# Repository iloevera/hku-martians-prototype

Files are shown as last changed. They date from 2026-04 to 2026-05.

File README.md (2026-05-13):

# HKU Martians Prototype Rover

Rudimentary 2-layer all-in-one Power Distribution Board (PDB) and logic carrier designed for small 6-wheel rovers with a 4-DoF robotic arm.

PCB preview

## 🚀 Key Specifications
- **Dimensions:** 99.57 x 99.06 mm
- **Power Input:** 6S LiPo (22.2V nominal, 25.2V max) via XT60.
- **Power Tree:**
  - **12V @ 10.8A:** High-current rail for BLDC/DC Main Drive motors. External module attached through XT30 connectors
  - **7.5V @ 5A:** Dedicated HV Servo rail (Optimized for 7.4V nominal servos). External module attached through XT30 connectors
  - **5.1V @ 5A:** On-board stabilized logic power for Pi 5 and peripherals. 3V3 Using Pico's built-in regulator.
- **Processing:**
  - Dual-core architecture: Raspberry Pi 5 (Thinking) + Pi Pico 2 (Doing).
  - UART communication bridge.
- **Actuation & Sensing:**
  - 6x PWM Encoder inputs.
  - 6x PWM-Controlled DC motor driver headers.
  - 4x High-Torque Servo ports with localized bulk capacitance.
  - Integrated 6S Battery Fuel Gauge (Voltage Divider + ADC).

## 🛠 Hardware Setup
### Battery Monitor Calibration
The internal voltage divider uses a **100kΩ (Top)** and **13.7kΩ (Bottom)** 1% precision resistor set. 
- **Max Input:** 25.2V
- **ADC Output:** ~3.03V
- **Safety Factor:** 10% headroom to prevent Pico ADC overvoltage.

### Communication
The Pi 5 and Pico 2 communicate via UART.
- **Baud Rate:** 115200 (Default)
- **Pinout:** Pi GPIO 14/15 <-> Pico GPIO 0/1.

## ⚠️ Assembly Warnings
1. **Thermal Reliefs:** High-current pads (XT60, Regulators, Motors) have thermal reliefs **DISABLED**. Use a high-power chisel-tip iron and pre-heat the board to 100°C for assembly.
2. **Capacitors:** Ensure C1 & C2 (2000uF) is rated for 50V minimum.
3. **USB Isolation:** Always use a USB isolator when debugging the Pi/Pico while the main battery is connected to prevent back-powering your PC.

## 📜 License
This project is released under CERN-OHL-W-2.0 license. Designed by **Ilo Japar / HKU Martians**.

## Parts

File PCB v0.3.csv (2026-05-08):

Reference | Qty | Value | Taobao
C1,C6 | 2 | 1000u 50V (E) | https://item.taobao.com/item.htm?id=522579424493&skuId=4292850932858
C2,C3,C9 | 3 | 0.1u 50V 1206 (C) | https://item.taobao.com/item.htm?id=522554243102
C4 | 1 | 100n 50V 1206 (C) | https://item.taobao.com/item.htm?id=522554243102
C5,C7 | 2 | 470u 50V (E) | https://item.taobao.com/item.htm?id=565000050337&skuId=4839680676732
C8 | 1 | 100u 50V (E) | https://item.taobao.com/item.htm?id=564996742055&skuId=5731925888317
D1 | 1 | 14.7V | https://item.taobao.com/item.htm?id=695101953366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
D2 | 1 | SK1010C | https://item.taobao.com/item.htm?id=661190438436
D3 | 1 | SMAJ6.0A | https://item.taobao.com/item.htm?id=626801460817
D4,D5,D6,D7 | 4 | Green 0805 | https://item.taobao.com/item.htm?id=522554271548&skuId=5766142345201
F1 | 1 | 15A | https://item.taobao.com/item.htm?id=646550973988&upStreamPrice=131&skuId=5317343647485
F2 | 1 | 5A 1812 | https://detail.tmall.com/item.htm?id=680110340340&xxc=shop&skuId=5053061151671
J1 | 1 | XT60-M | https://item.taobao.com/item.htm?from=cart&id=635227665423&skuId=4544457080563&upStreamPrice=247
J2 | 1 | Raspberry Pi 5 | https://item.taobao.com/item.htm?id=522576768218&skuId=3150252041904
J3,J5 | 2 | XT30-F | https://item.taobao.com/item.htm?from=cart&id=635227665423&skuId=4544457080563&upStreamPrice=247
J4,J6 | 2 | XT30-M | https://item.taobao.com/item.htm?from=cart&id=635227665423&skuId=4544457080563&upStreamPrice=247
J7,J8,J9,J10 | 4 | 2.54mm 3P | https://item.taobao.com/item.htm?id=522579376259&skuId=6139961763384
J11,J12,J13,J14,J15,J16 | 6 | 2.54mm 5P Terminal Block | https://item.taobao.com/item.htm?id=642057328277&skuId=4619071856328
J17,J18,J19,J20,J21,J22 | 6 | JST-SH 3P | https://item.taobao.com/item.htm?id=616913039189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
Q1 | 1 | NCE15P25JK | https://item.taobao.com/item.htm?from=cart&id=810052647977&upStreamPrice=155
R1,R2 | 2 | 100k 0805 1% | https://item.taobao.com/item.htm?id=526088038633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
R3 | 1 | 13.3k 0805 1% | https://item.taobao.com/item.htm?id=526088038633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
R4,R5,R6,R7,R8,R9 | 6 | 470R 0805 | https://item.taobao.com/item.htm?id=522573121620&skuId=5702455484812
TP1,TP2,TP3,TP4,TP5,TP6 | 6 | TestPoint
U1 | 1 | 3.2~32V -> 5.1V 5A | https://item.taobao.com/item.htm?id=530479908999

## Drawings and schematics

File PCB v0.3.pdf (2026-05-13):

GPIO0 1 | GPIO1 2 | GND

# ADC_VREF 35 ³V3 36

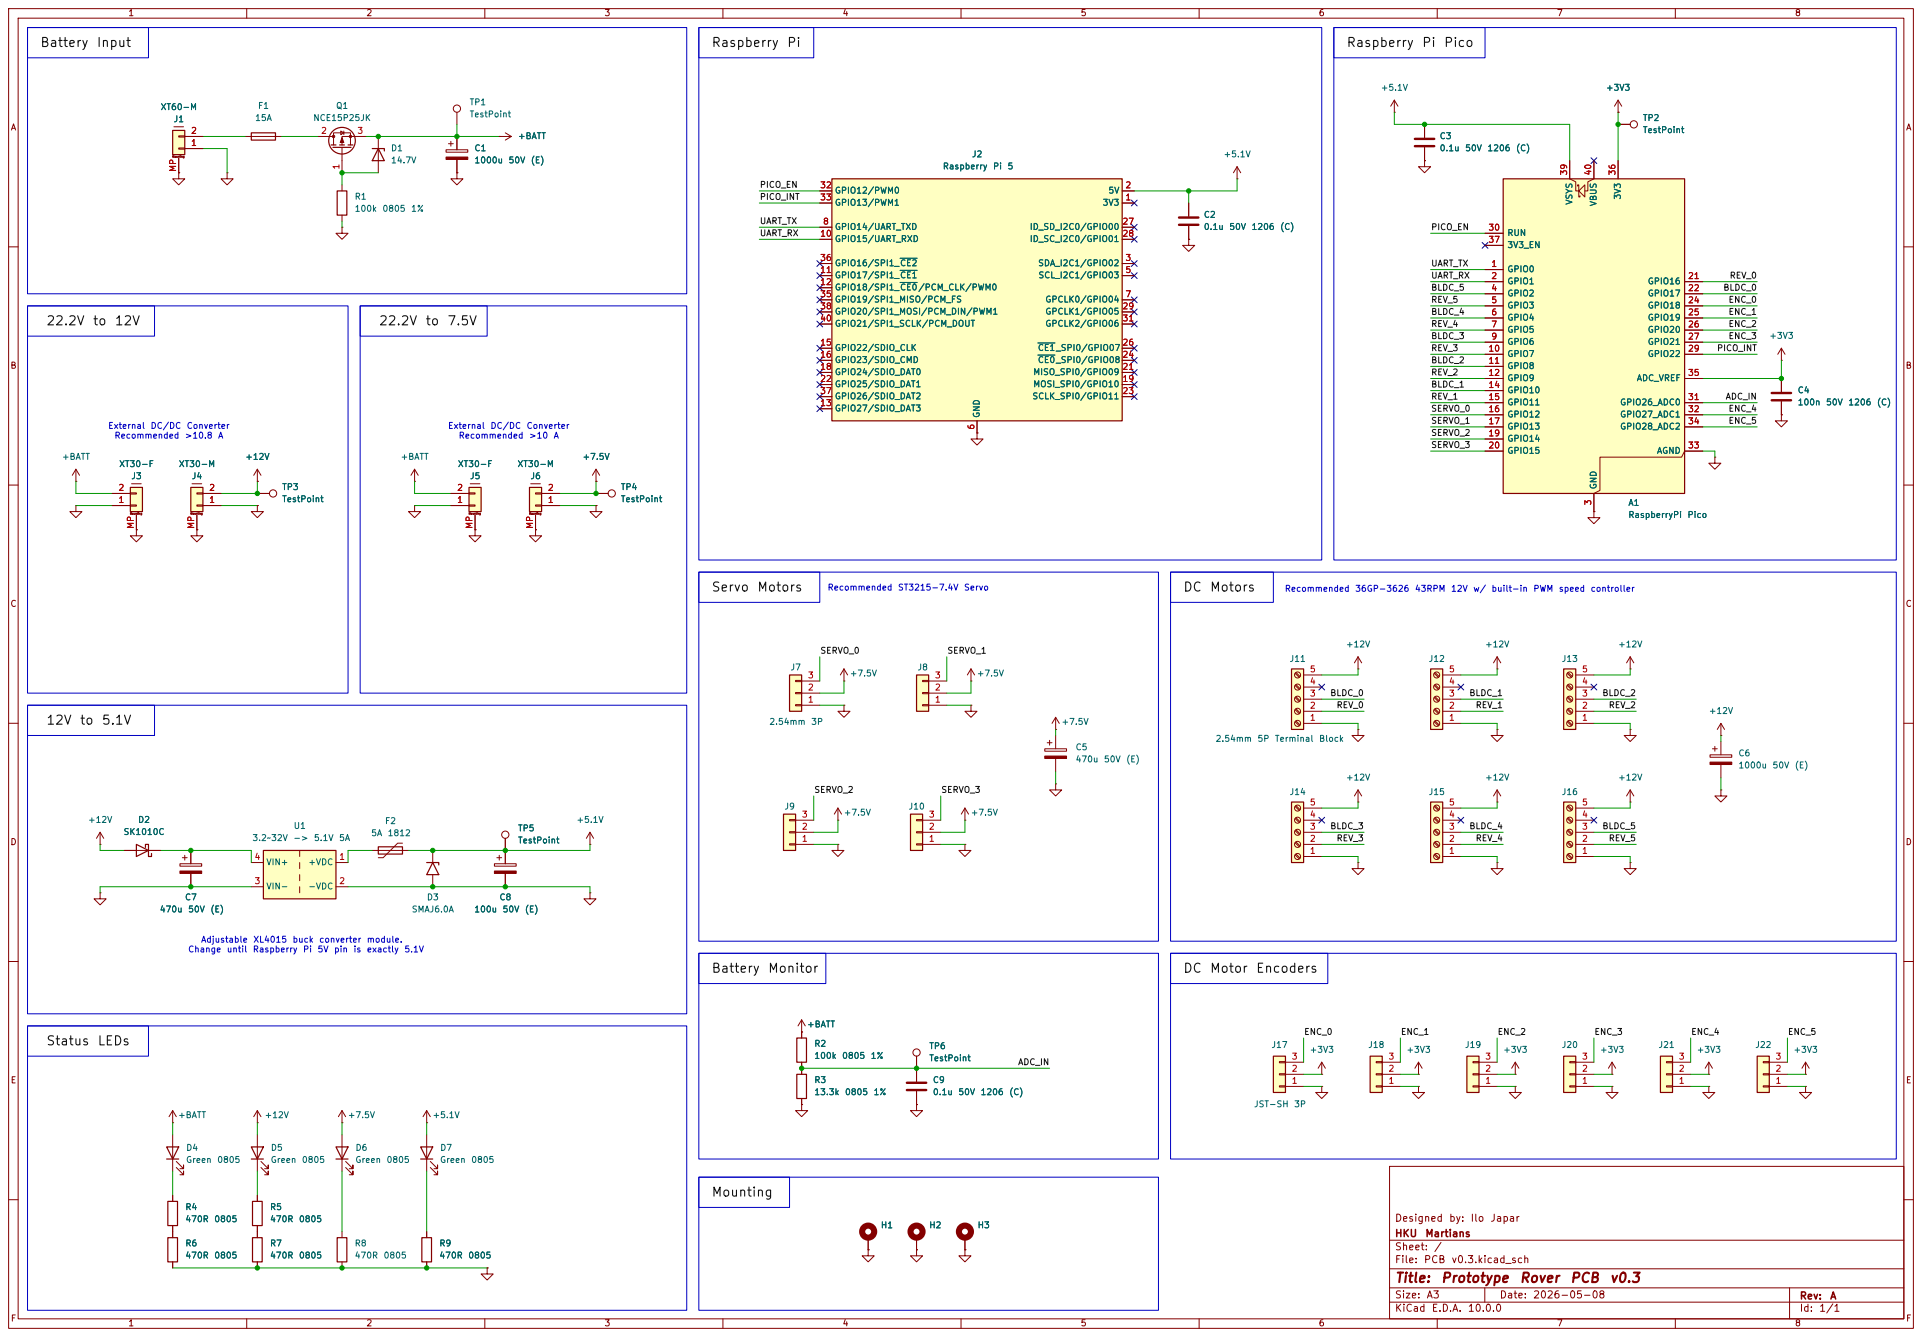
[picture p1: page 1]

Sheet: /
File: PCB v0.3.kicad_sch
Title: Prototype Rover PCB v0.3
F Date: 2026⁻05⁻08 KiCad E.D.A. 10.0.0

Q1 U1 | 99.57 mm 99.06 mm

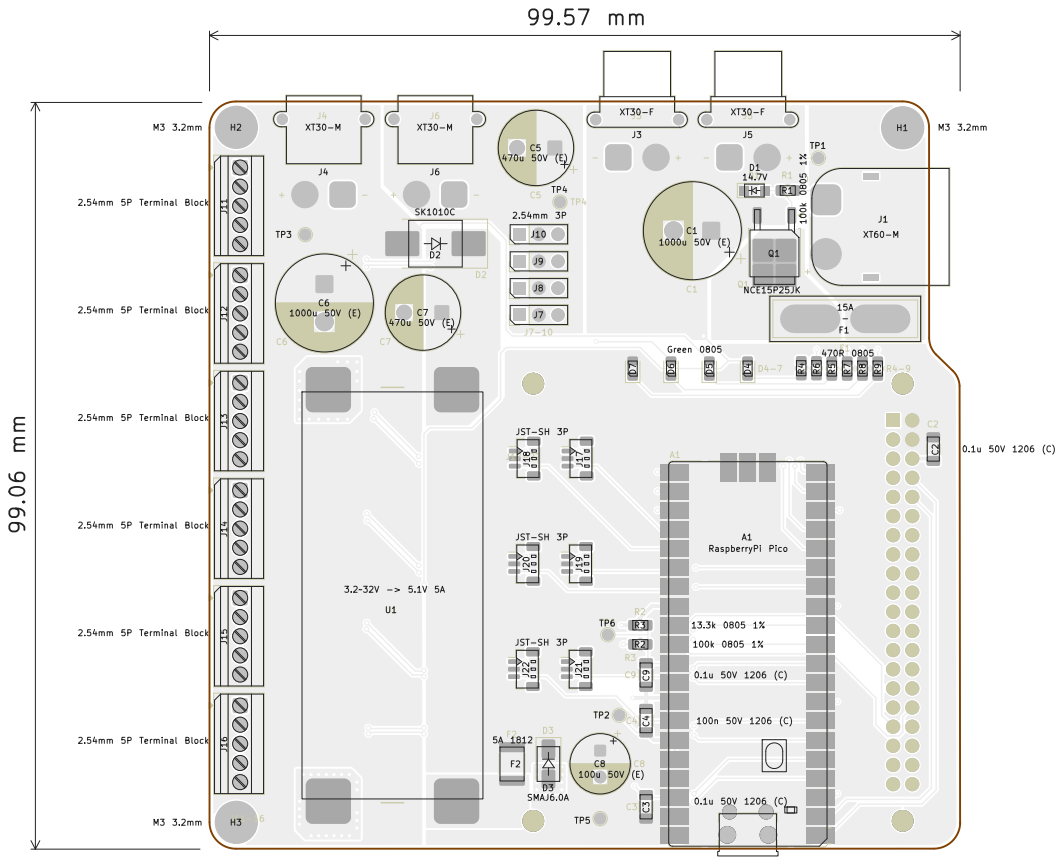
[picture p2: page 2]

Board2Pdf: Light Colors Placement TOP - Page 1/2

Sheet: Light Colors Placement TOP HKU Martians Designed by: Ilo Japar

D Date: 2026⁻04⁻10 KiCad E.D.A. 10.0.0
File: PCB v0.3.kicad_pcb
Title: Prototype Rover PCB v0.3

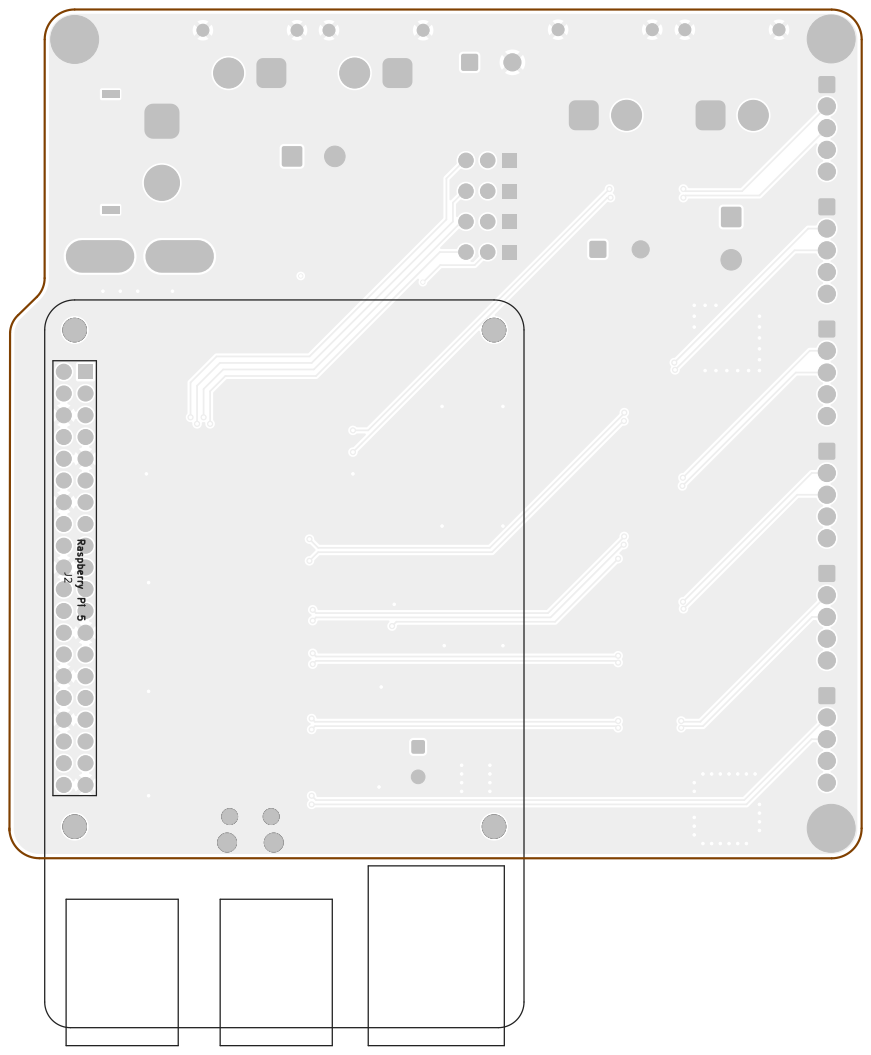
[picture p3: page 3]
J2 Raspberry Pi 5 1 2 3 4 5 6

Board2Pdf: Light Colors Placement BOT - Page 2/2

Sheet: Light Colors Placement BOT HKU Martians Designed by: Ilo Japar

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

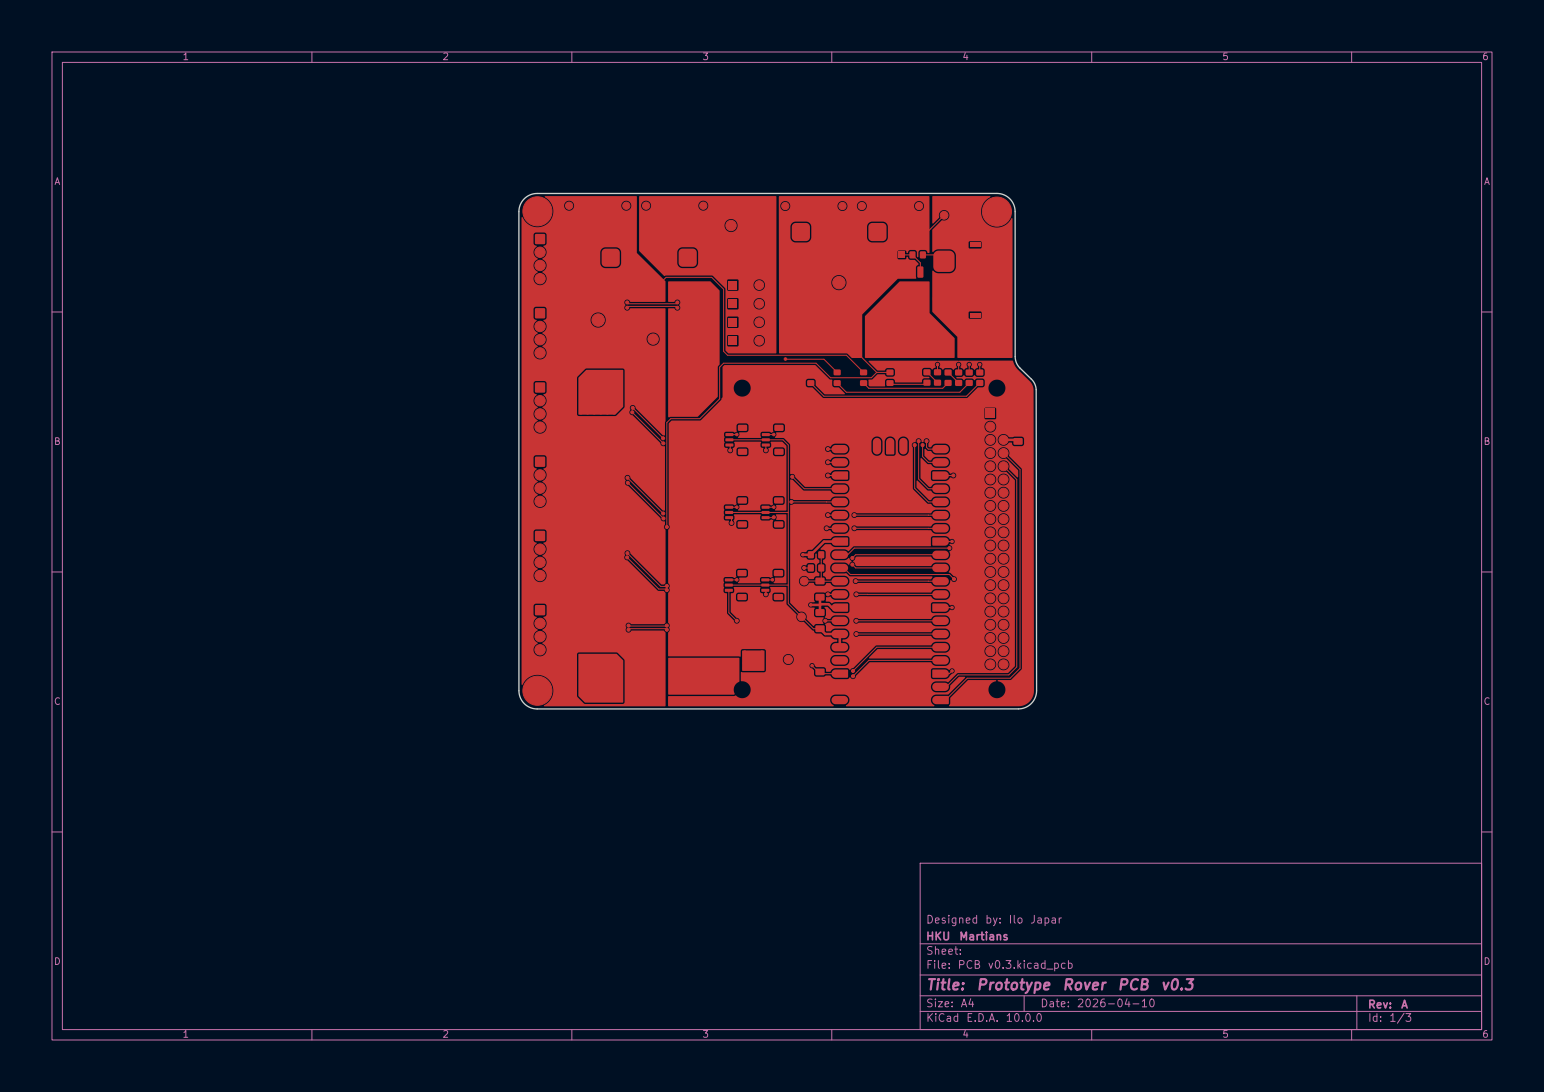
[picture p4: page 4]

HKU Martians Designed by: Ilo Japar

Sheet:
D Date: 2026⁻04⁻10 KiCad E.D.A. 10.0.0
File: PCB v0.3.kicad_pcb
Title: Prototype Rover PCB v0.3

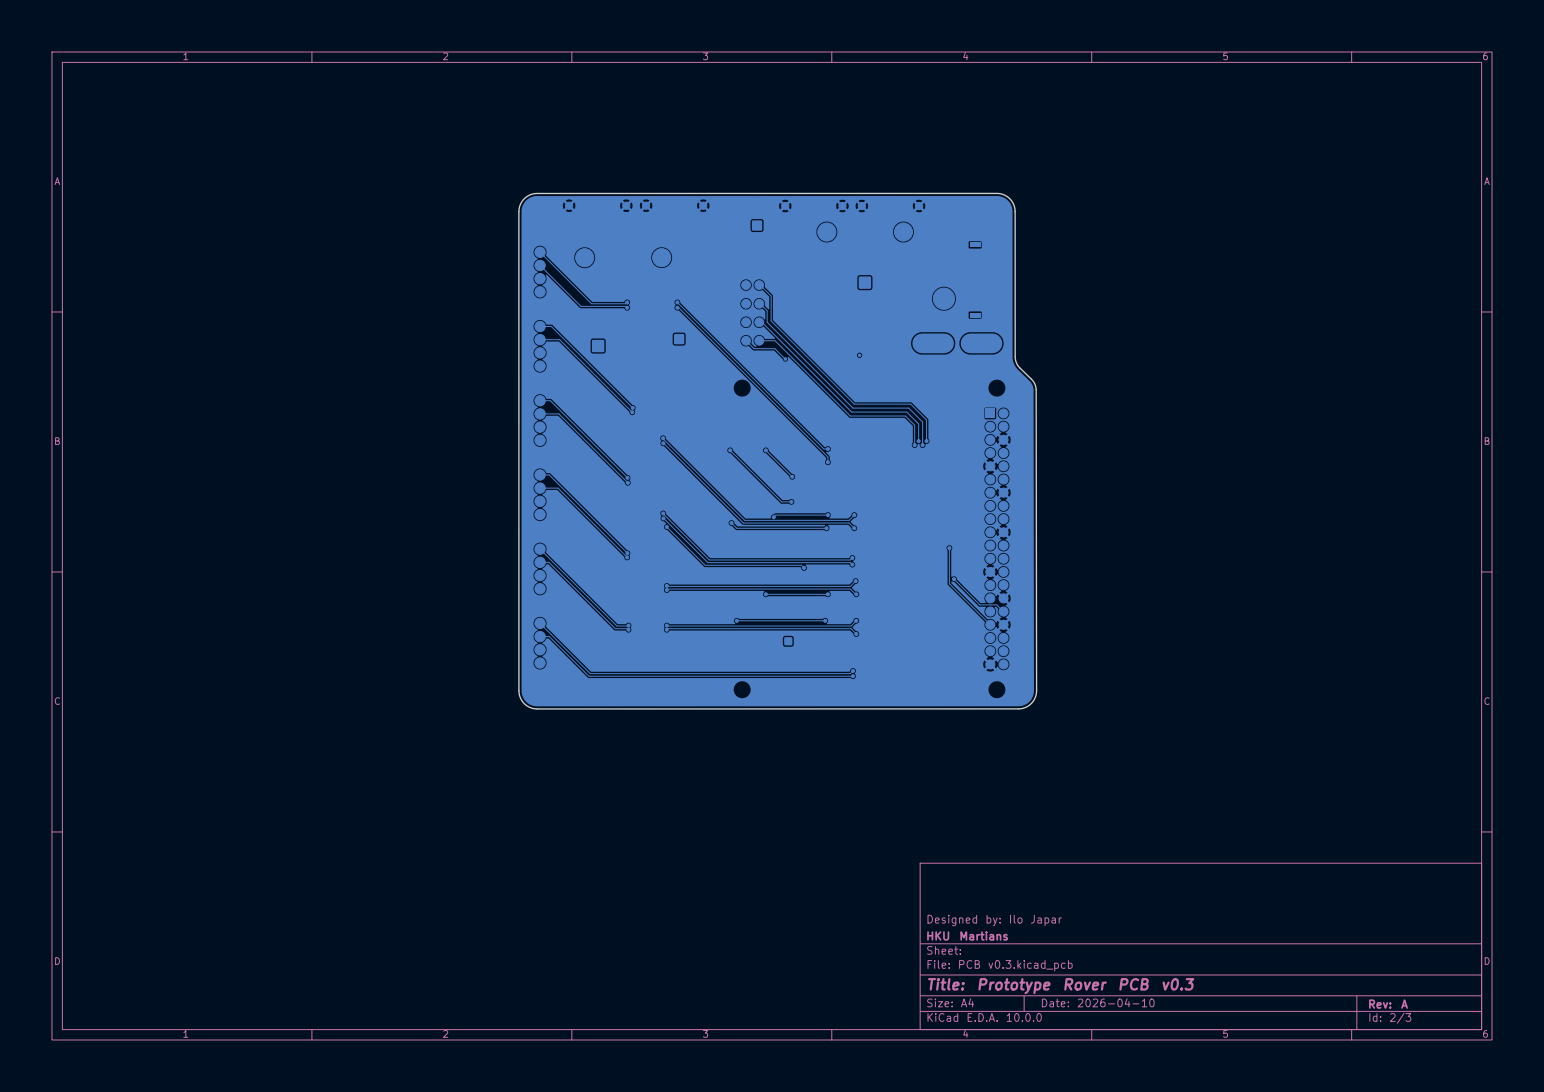
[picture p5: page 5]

HKU Martians Designed by: Ilo Japar

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

F2 | R2 C5 | R3

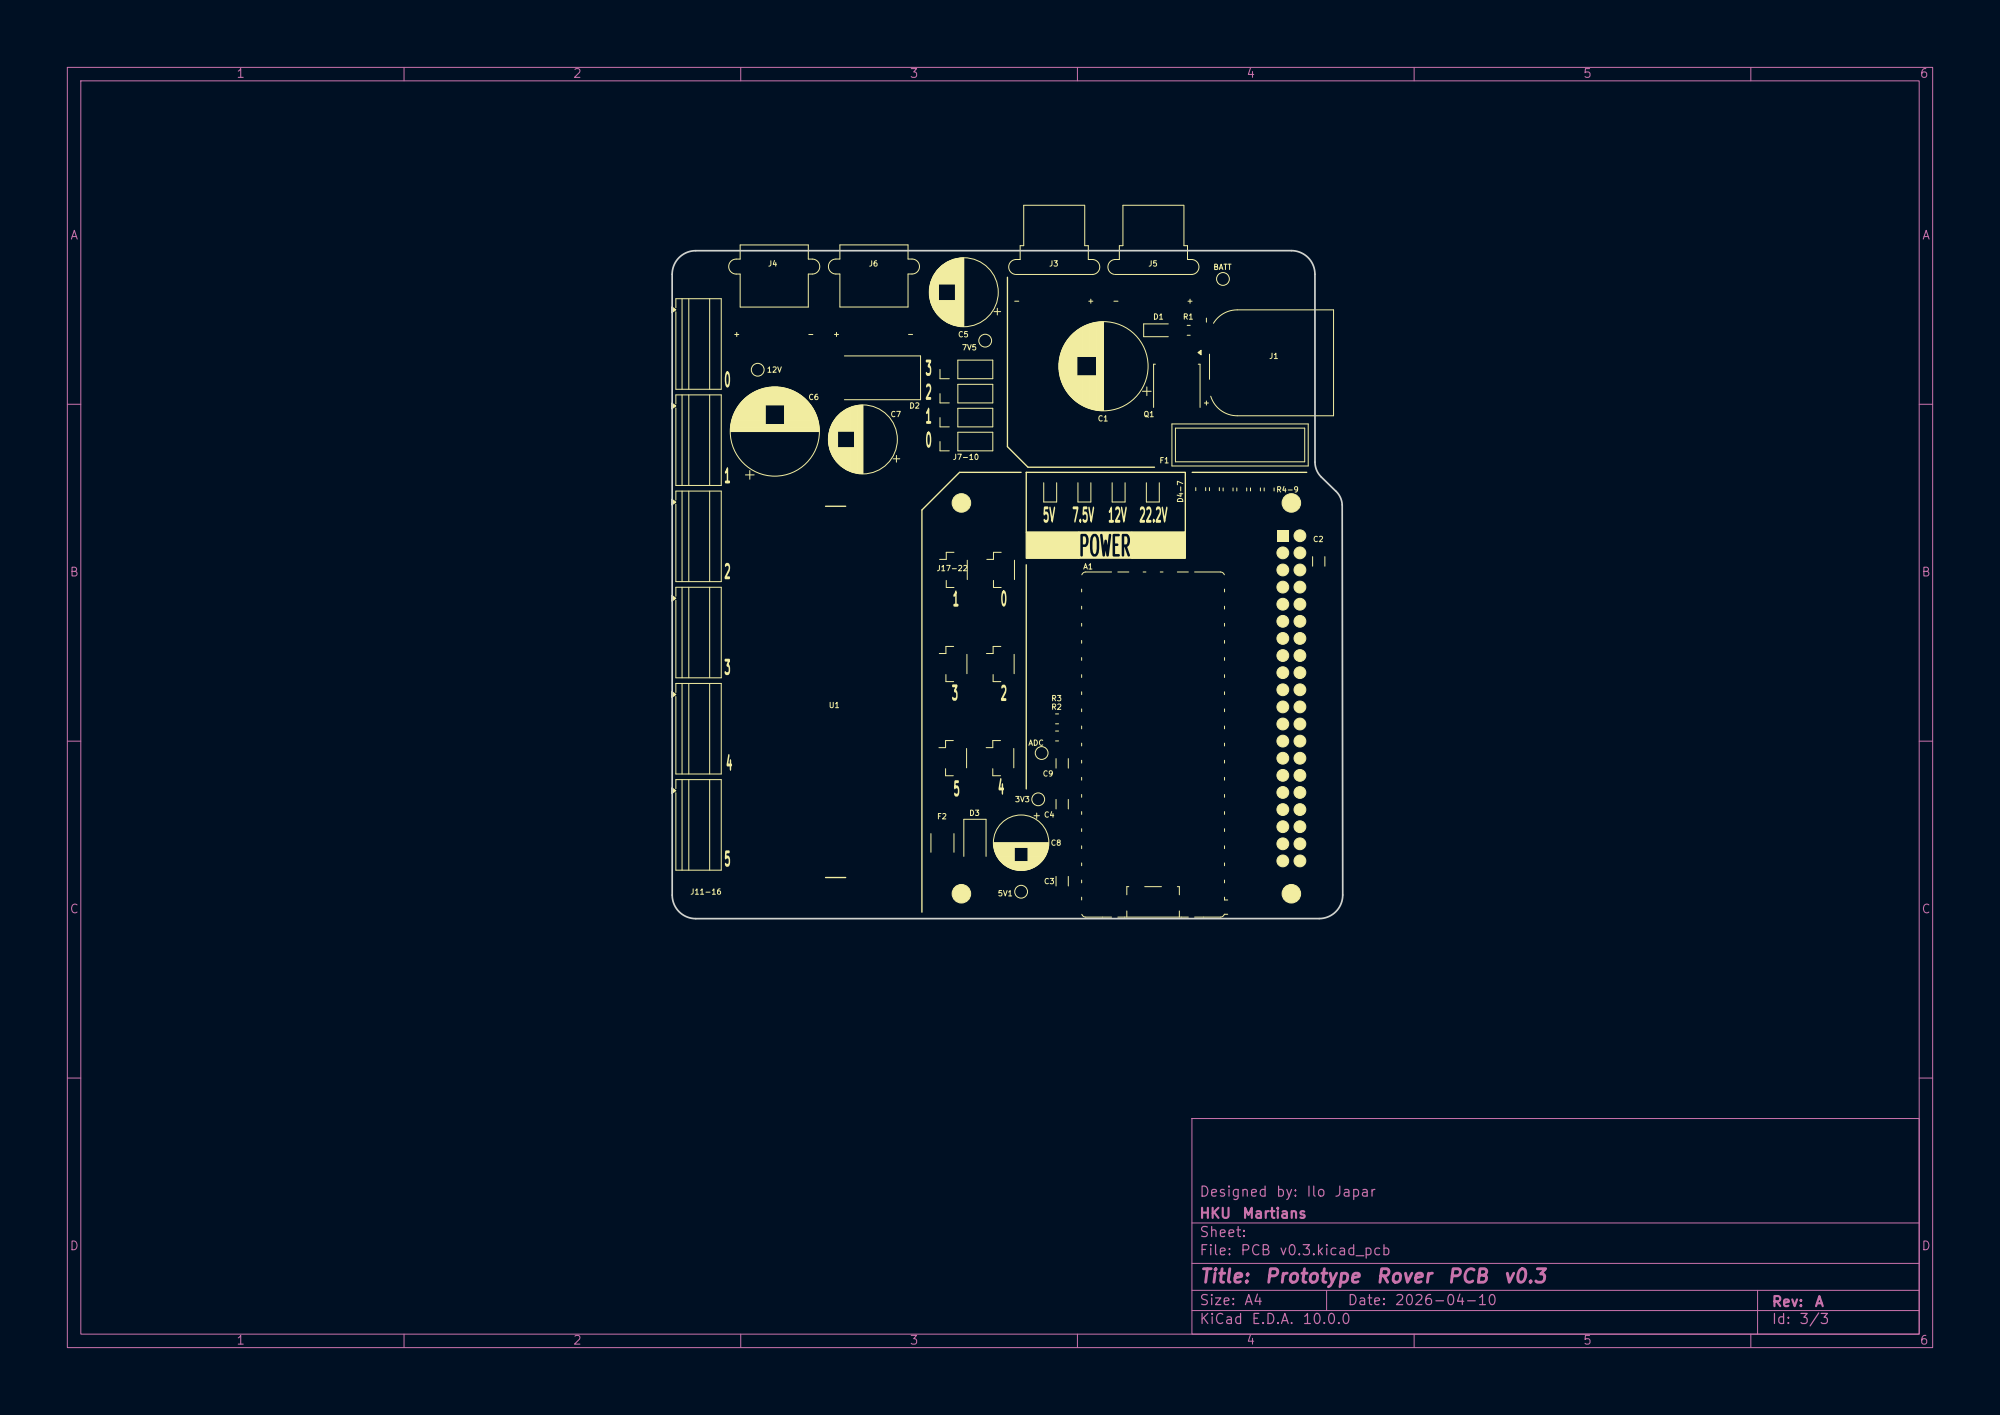
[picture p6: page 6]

HKU Martians Designed by: Ilo Japar

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

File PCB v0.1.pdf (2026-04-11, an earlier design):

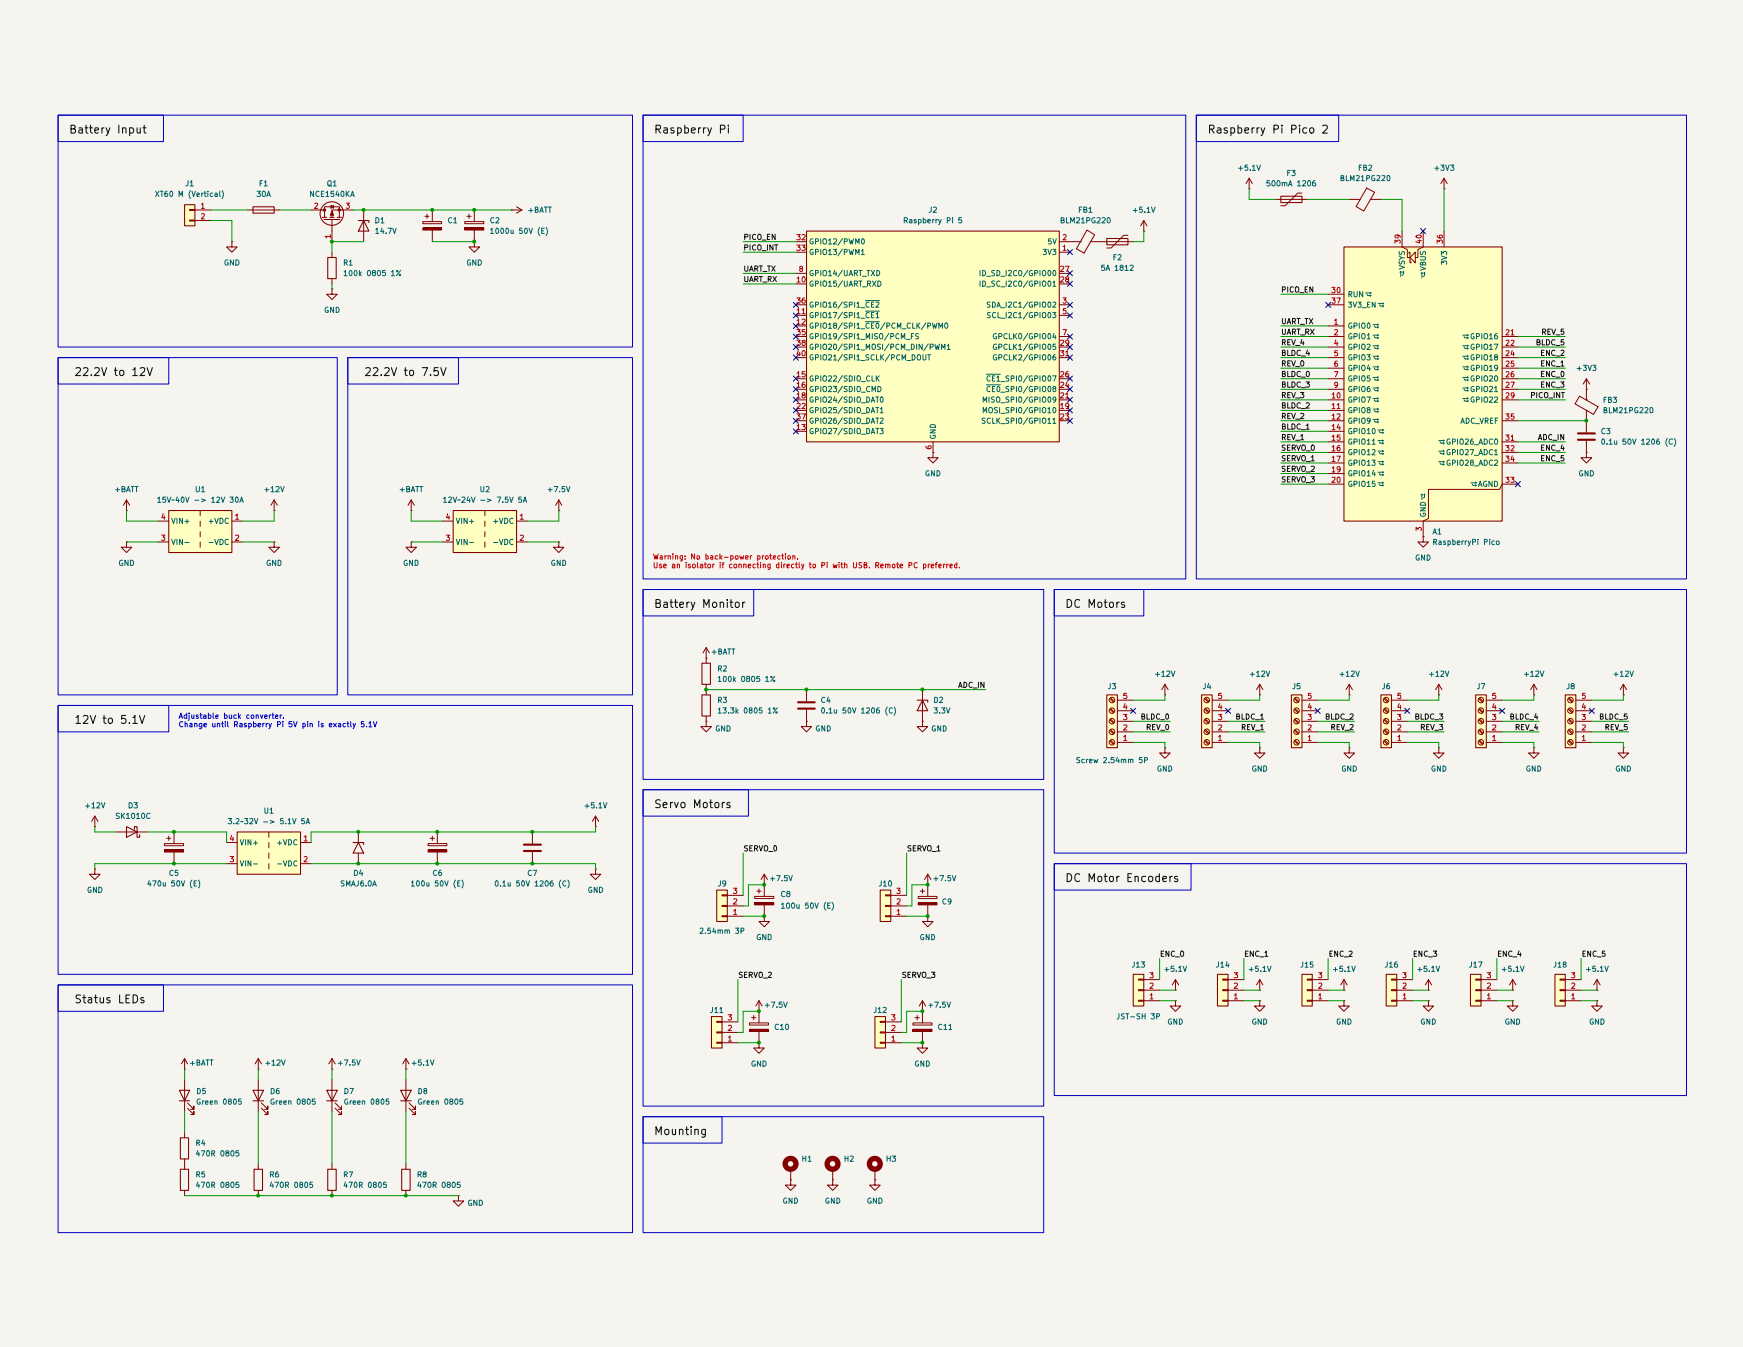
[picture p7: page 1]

# J3⁻8 D5⁻⁸ R4⁻⁸ J13⁻¹⁸

J6 | R5 SK1010C D3 | 2.54mm ³P J12

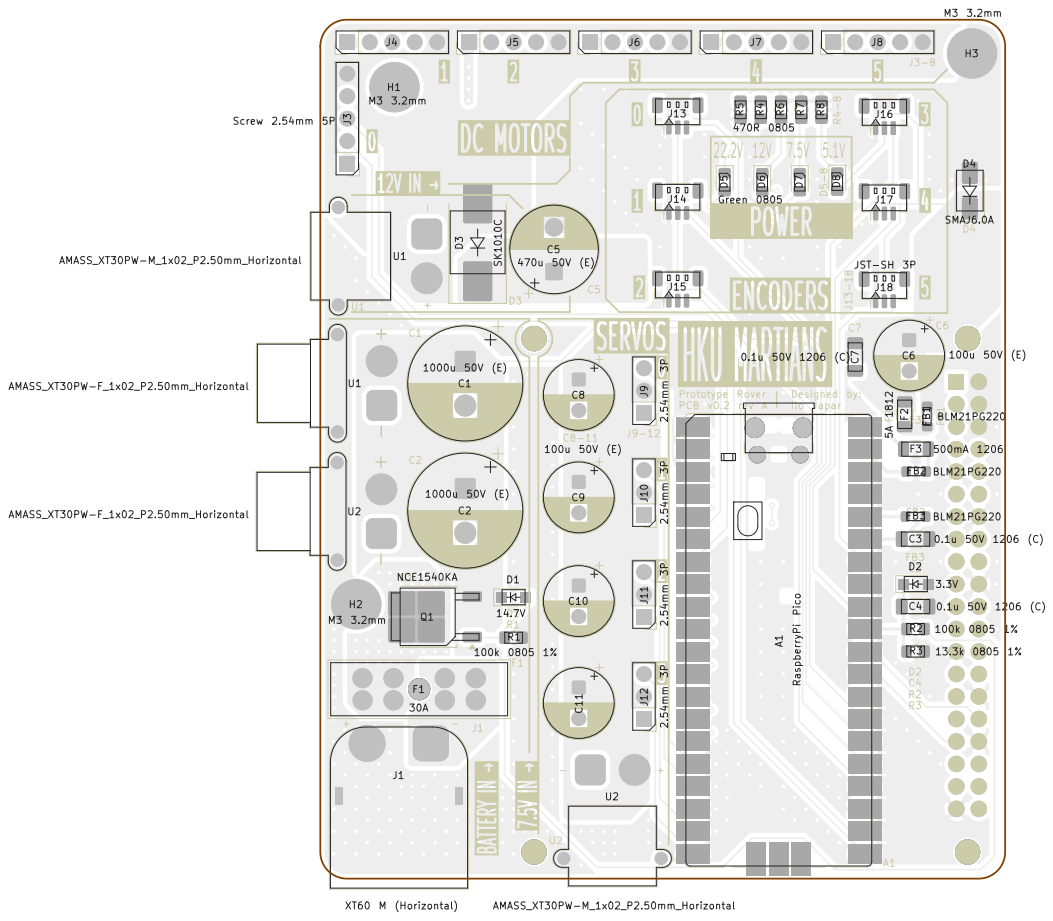
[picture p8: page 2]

Board2Pdf: Light Colors Placement TOP - Page 1/2

Designed by: Ilo Japar
Sheet: Light Colors Placement TOP HKU ROVER Team

D Date: 2026⁻04⁻10 KiCad E.D.A. 10.0.0
File: PCB v0.1.kicad_pcb
Title: Prototype Rover PCB v0.1

AB

AB

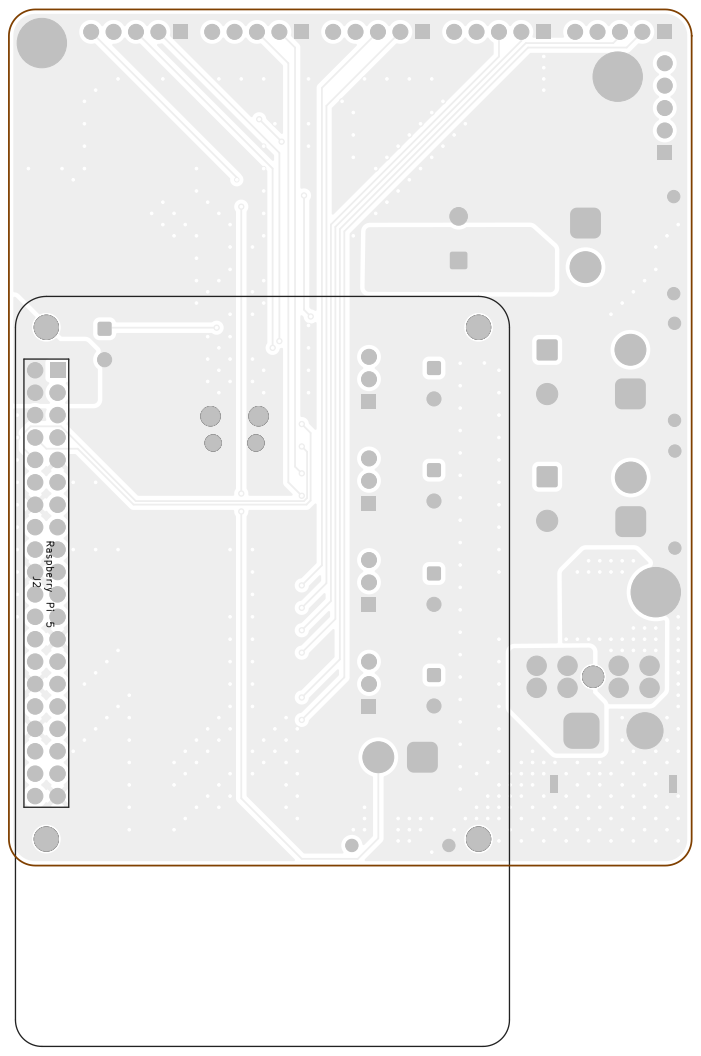
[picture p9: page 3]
J2 Raspberry Pi 5 1 2 3 4 5 6; Size: A4; Rev: A

Board2Pdf: Light Colors Placement BOT - Page 2/2

Designed by: Ilo Japar
Sheet: Light Colors Placement BOT HKU ROVER Team

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

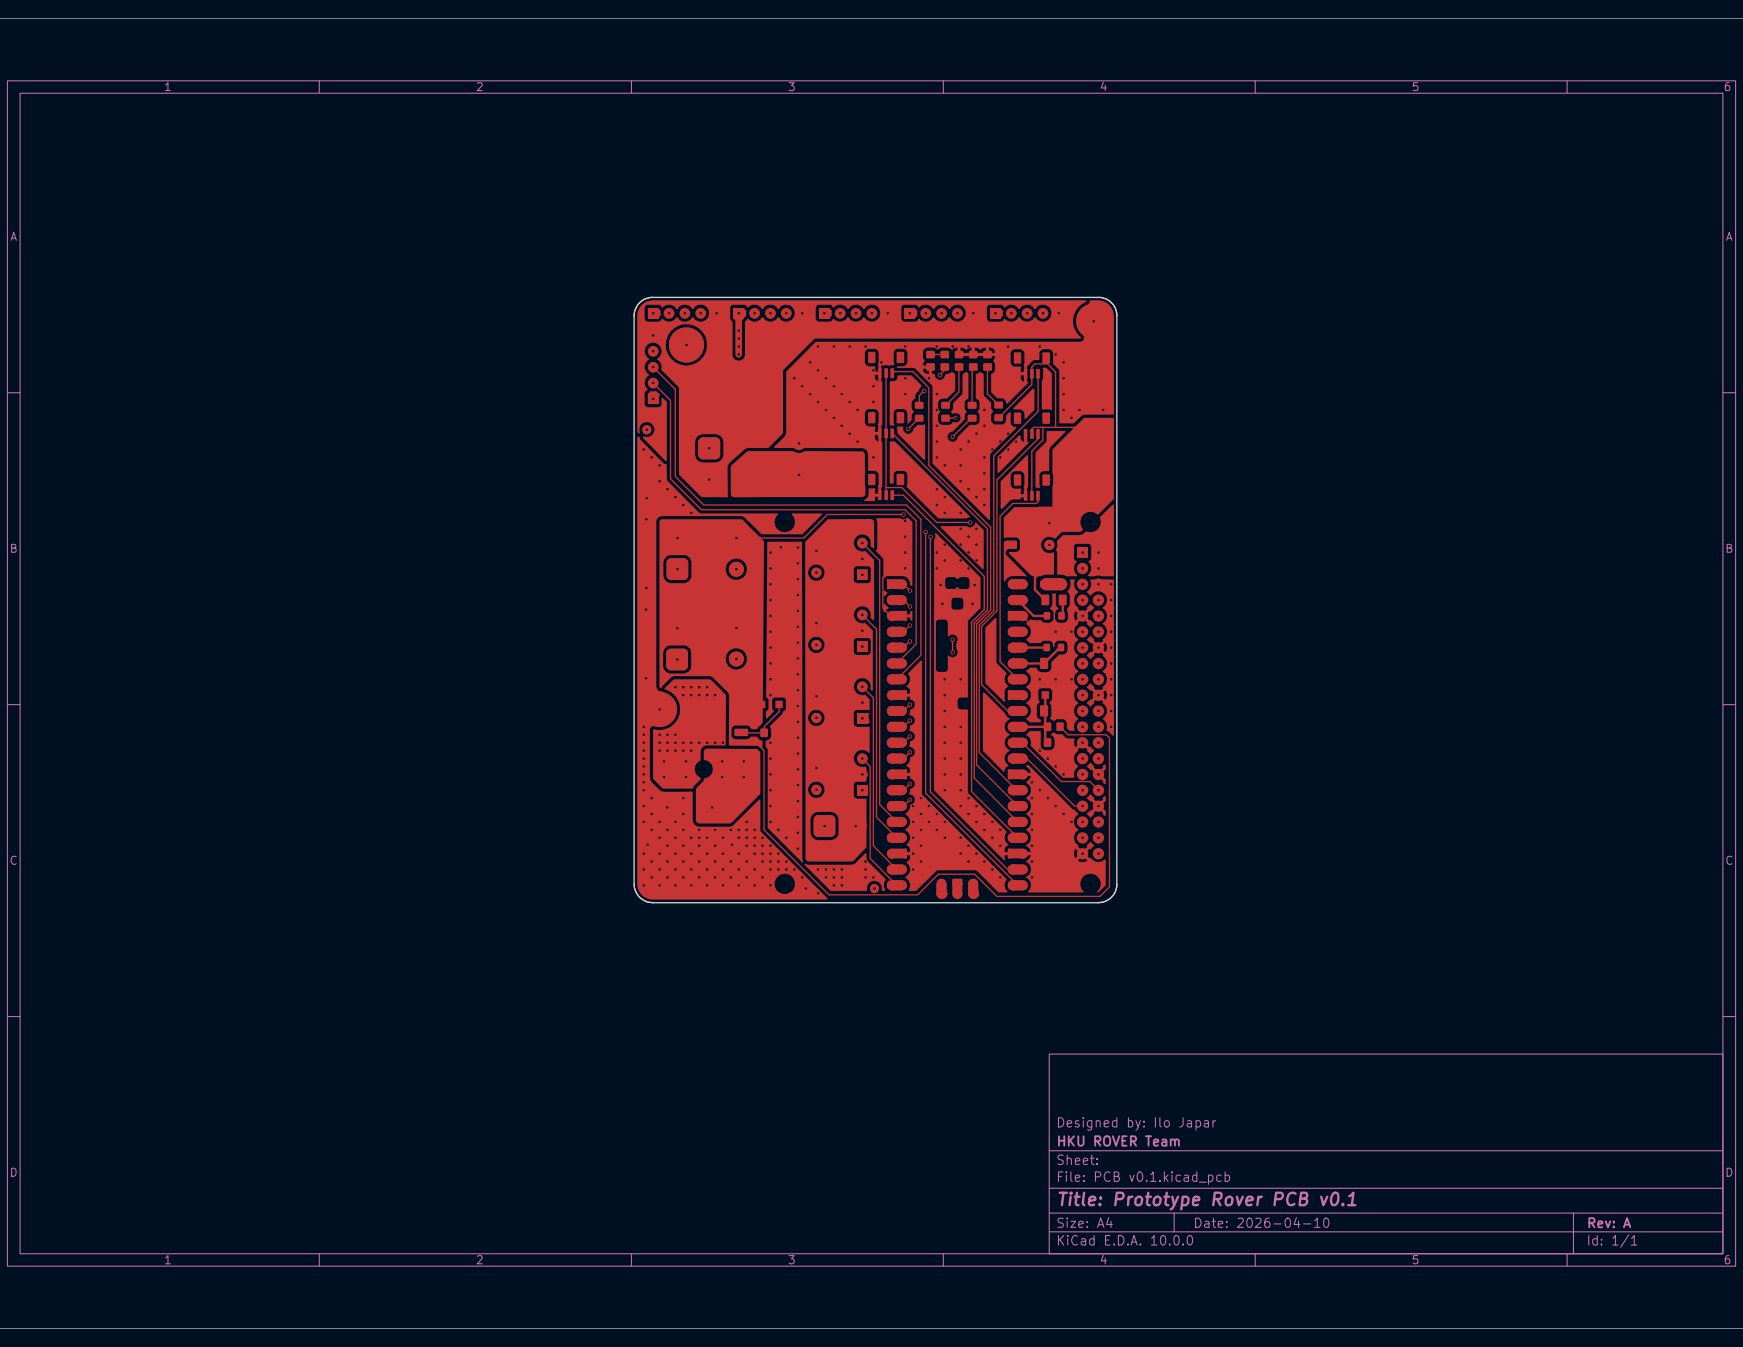
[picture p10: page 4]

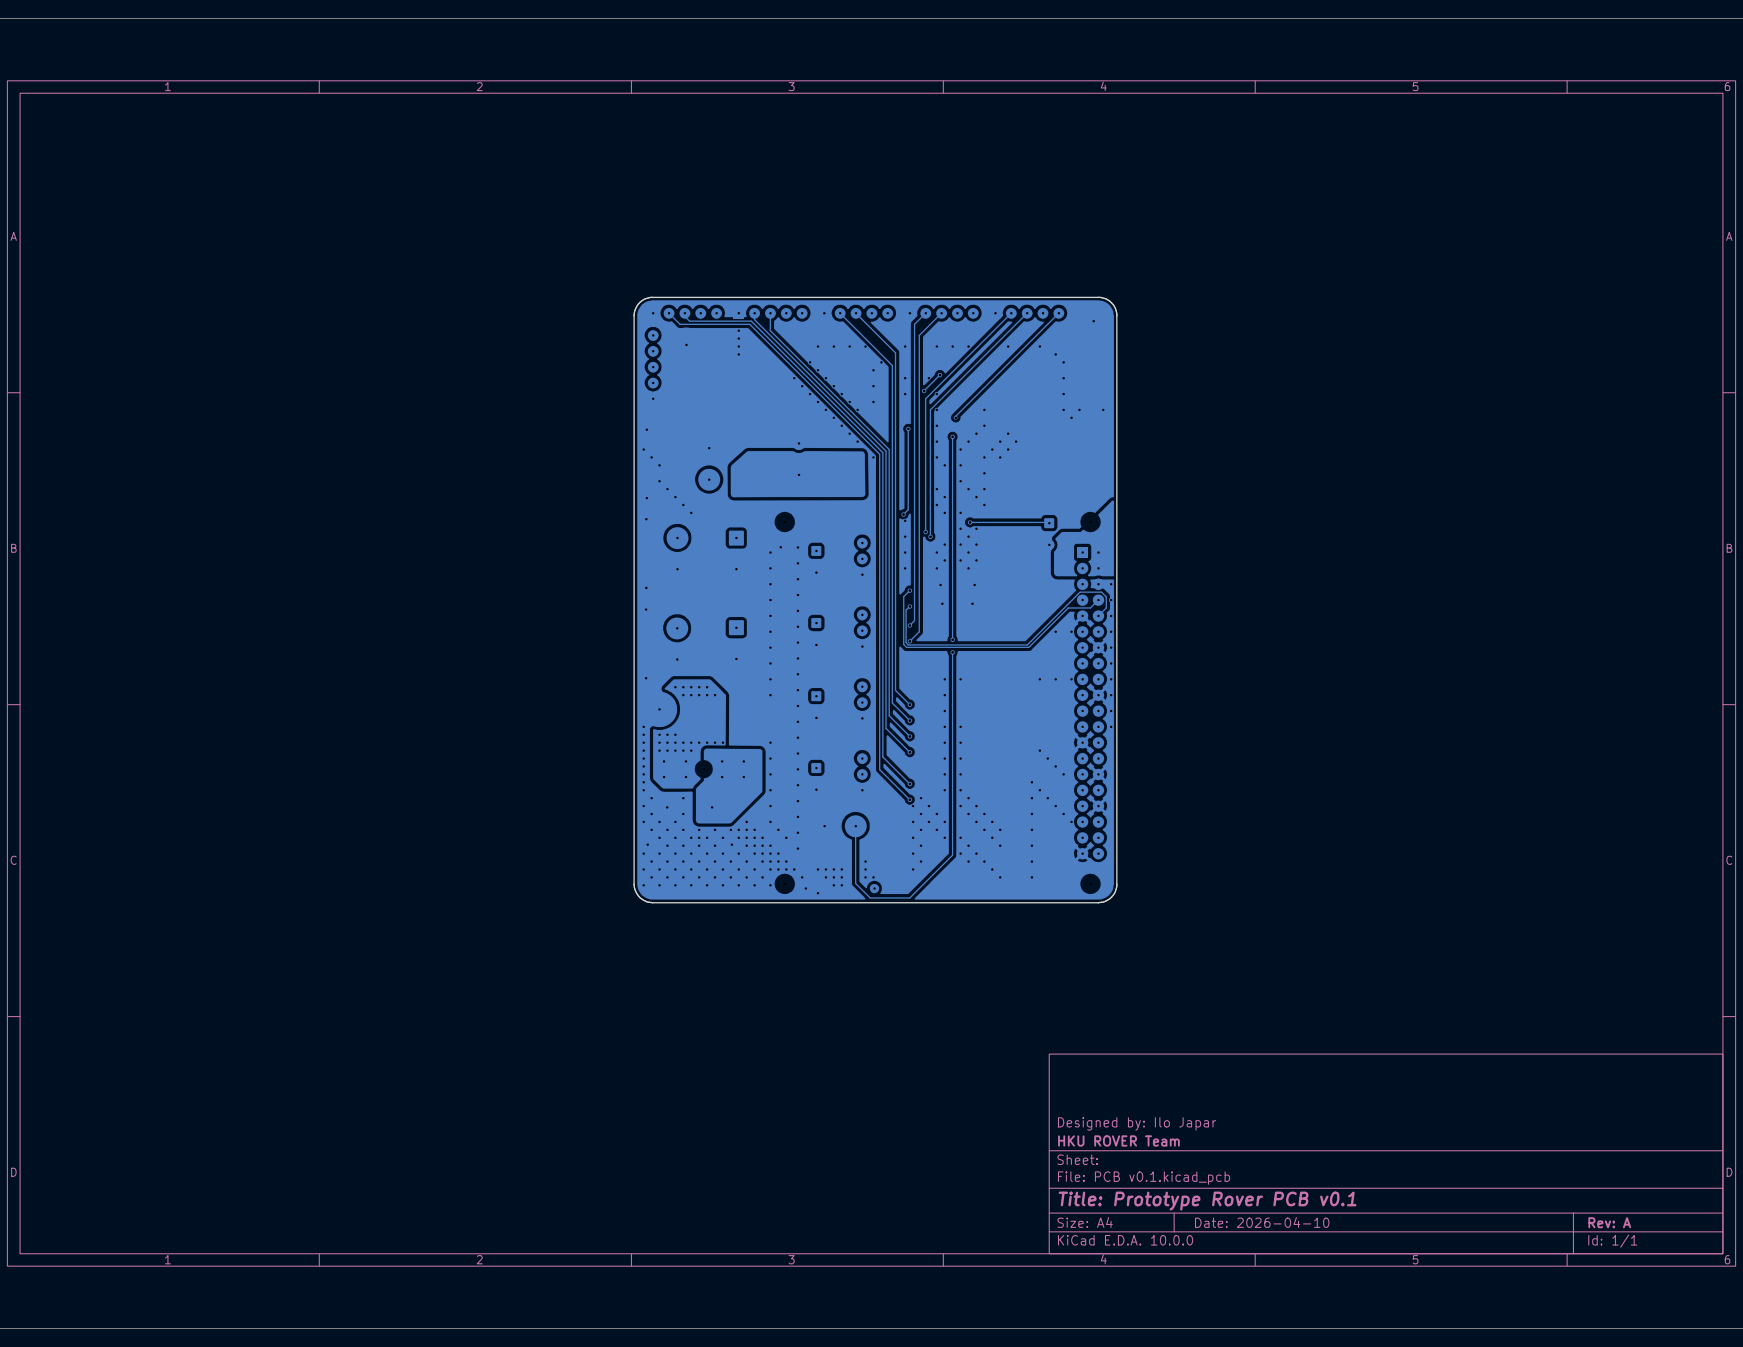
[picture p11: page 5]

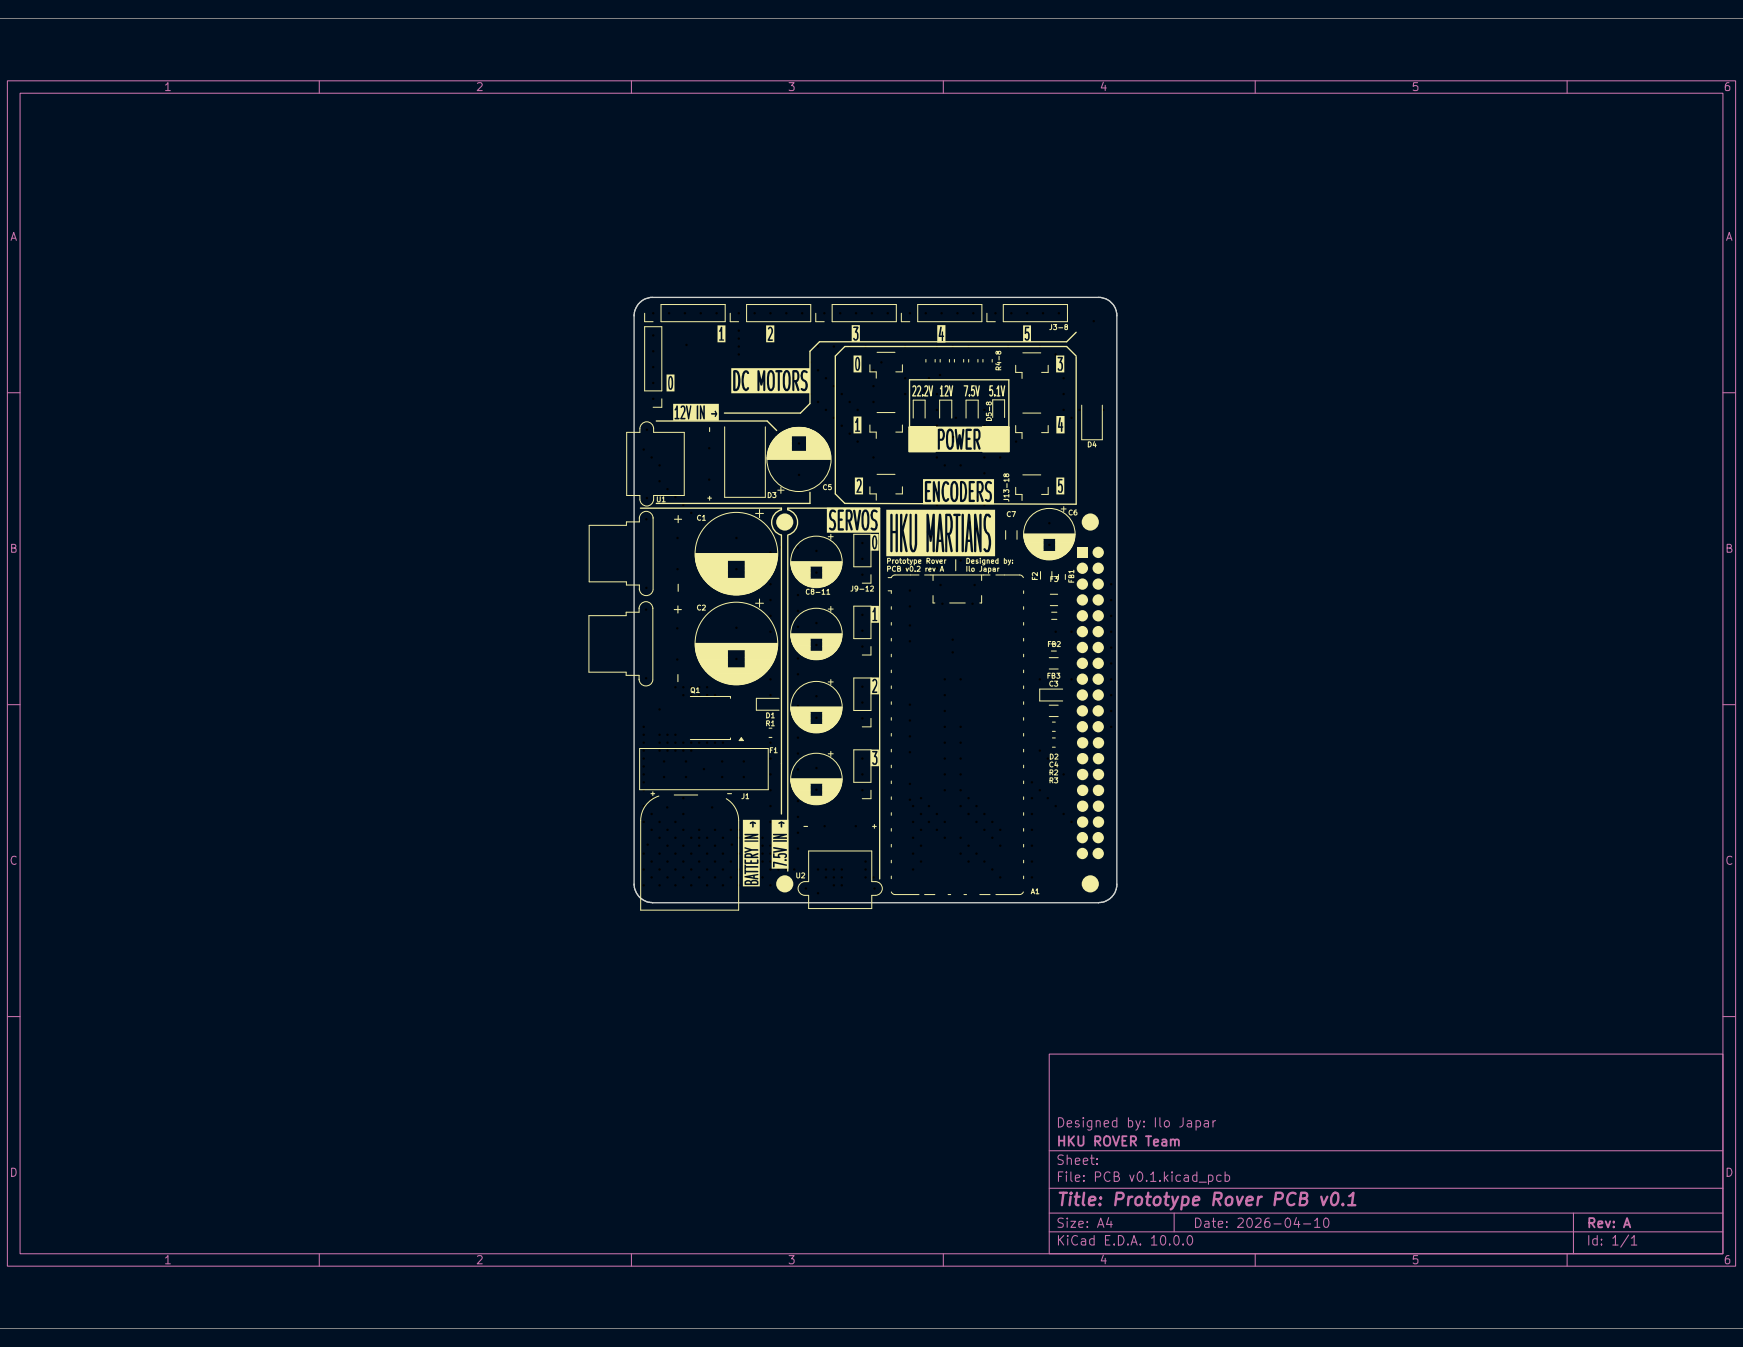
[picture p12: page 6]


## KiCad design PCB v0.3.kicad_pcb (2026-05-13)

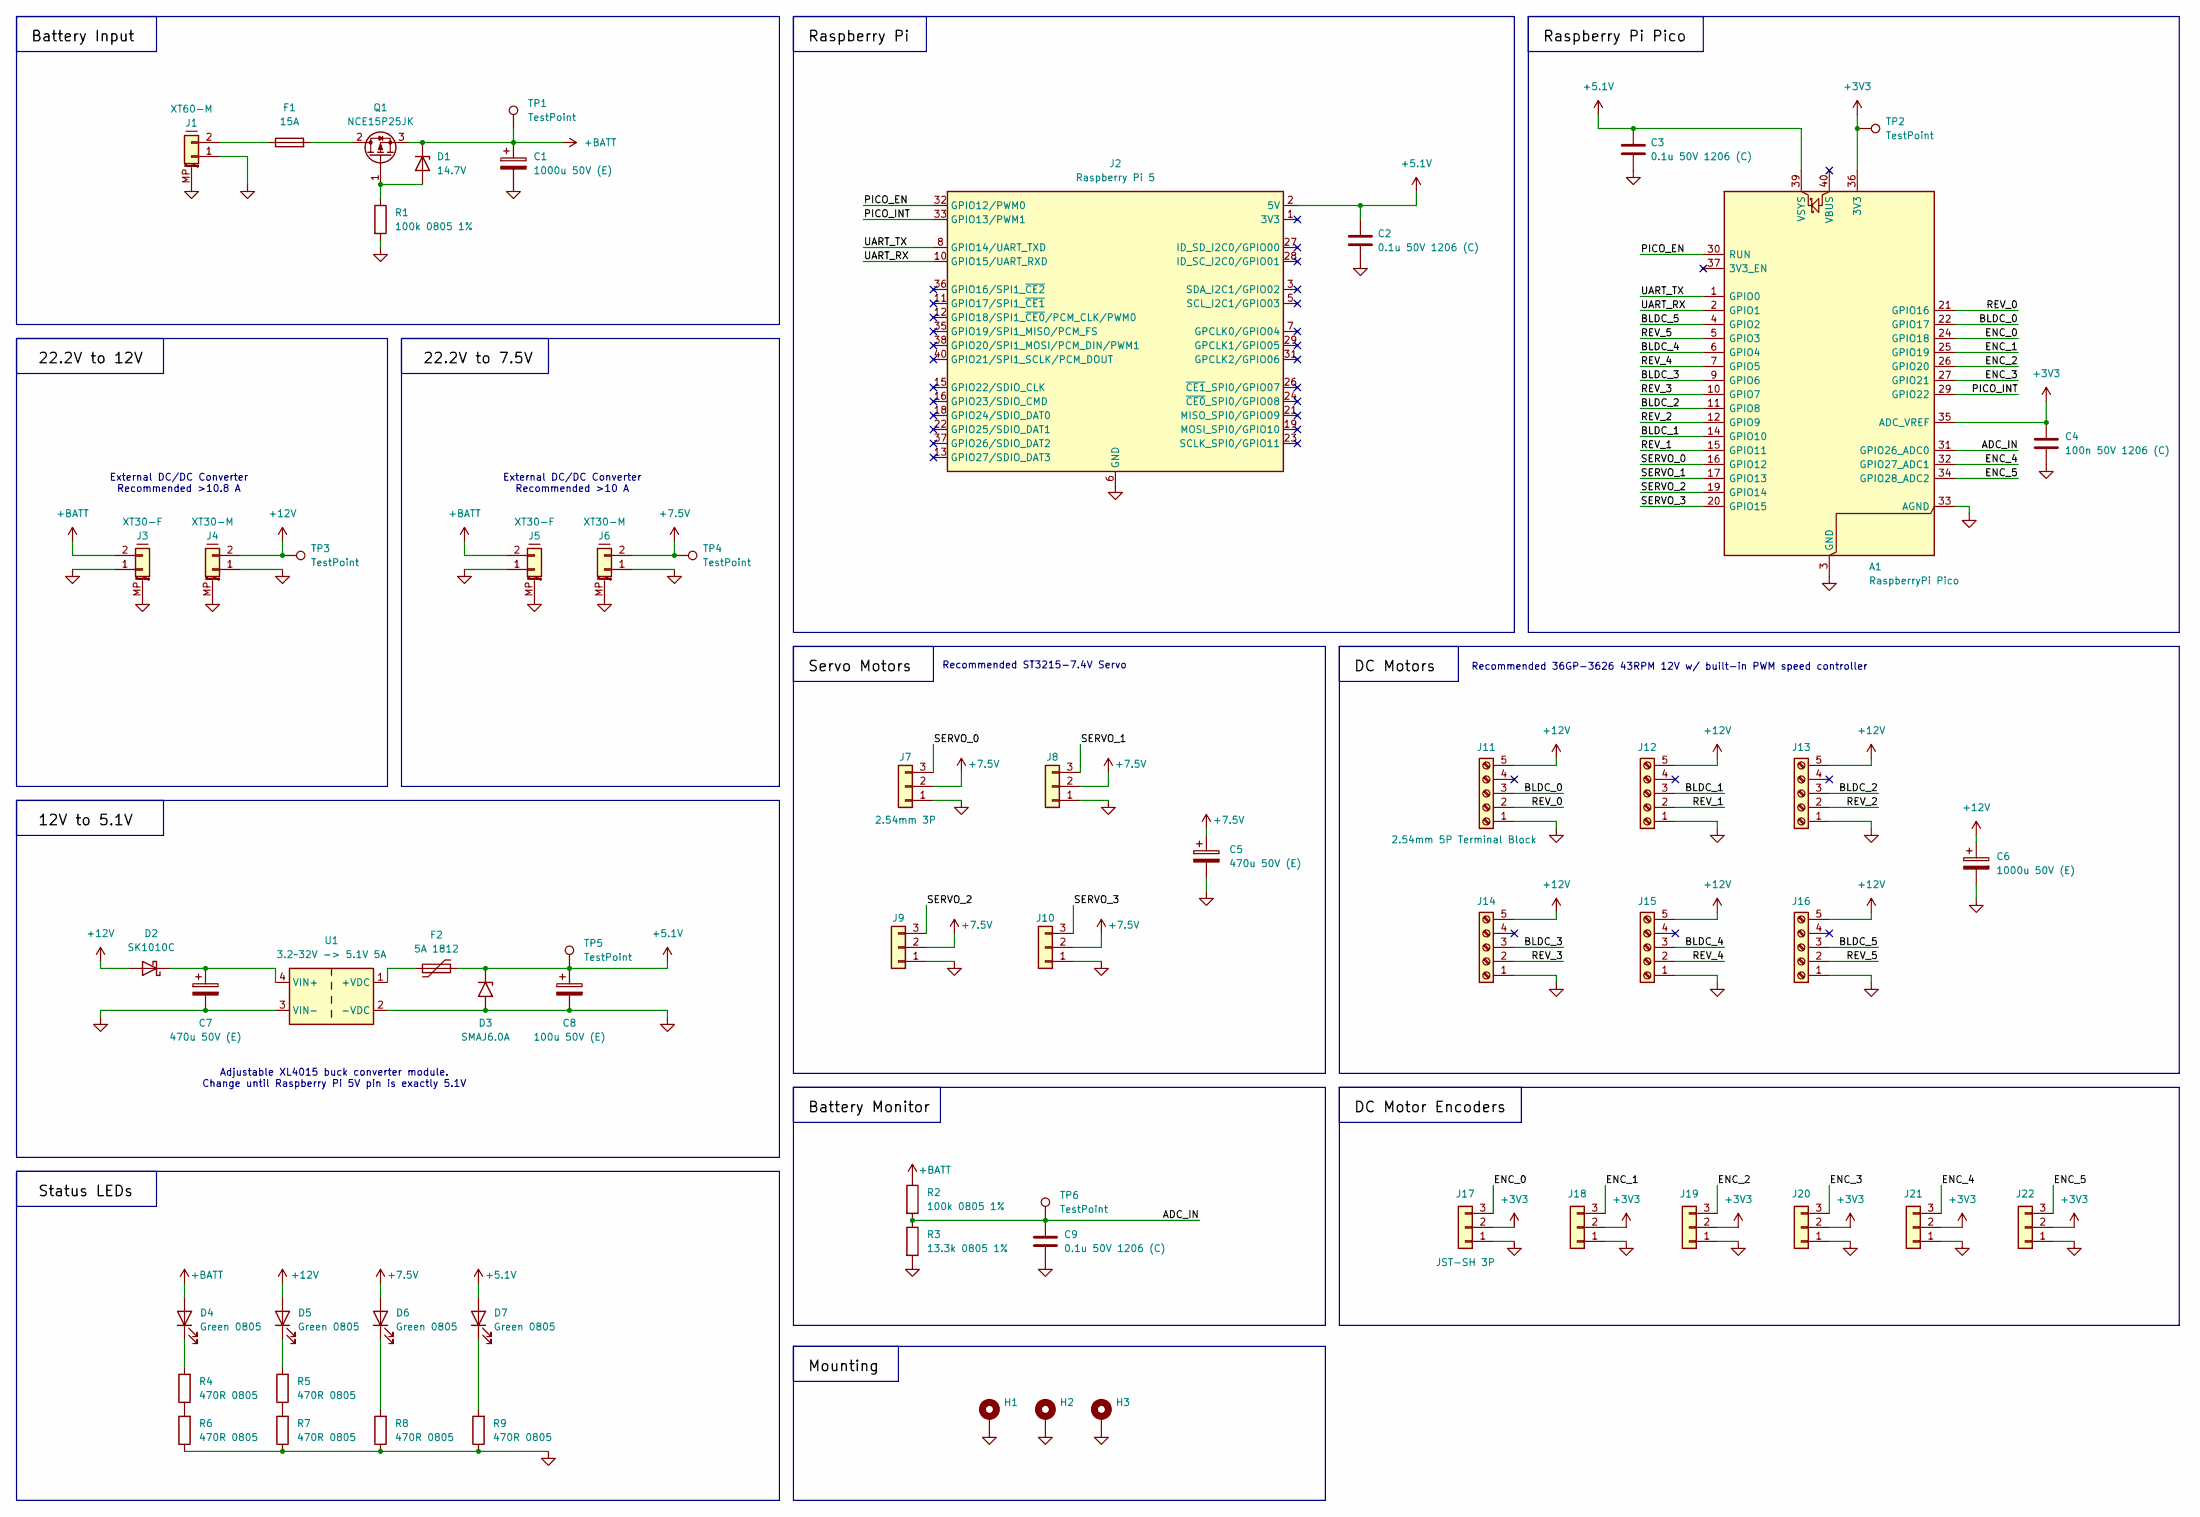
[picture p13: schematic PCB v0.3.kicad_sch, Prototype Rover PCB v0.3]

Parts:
A1: RaspberryPi Pico; RaspberryPi_Pico_SMD_HandSolder
C1, C6: 1000u 50V (E); CP_Radial_D13.0mm_P5.00mm
C2, C3, C9: 0.1u 50V 1206 (C); C_1206_3216Metric_Pad1.33x1.80mm_HandSolder
C4: 100n 50V 1206 (C); C_1206_3216Metric_Pad1.33x1.80mm_HandSolder
C5, C7: 470u 50V (E); CP_Radial_D10.0mm_P5.00mm
C8: 100u 50V (E); CP_Radial_D8.0mm_P3.50mm
D1: 14.7V; Nexperia_CFP3_SOD-123W
D2: SK1010C; D_SMC_Handsoldering
D3: SMAJ6.0A; D_SMA
D4, D5, D6, D7: Green 0805; LED_0805_2012Metric_Pad1.15x1.40mm_HandSolder
F1: 15A; Fuse_Blade_ATO_directSolder
F2: 5A 1812; Fuse_1812_4532Metric_Pad1.30x3.40mm_HandSolder
H1, H2, H3: M3 3.2mm; MountingHole_3.2mm_M3_DIN965_Pad
J1: XT60-M; AMASS_XT60PW-M_1x02_P7.20mm_Horizontal
J2: Raspberry Pi 5; raspberrypi_2_3
J3, J5: XT30-F; AMASS_XT30PW-F_1x02_P2.50mm_Horizontal
J4, J6: XT30-M; AMASS_XT30PW-M_1x02_P2.50mm_Horizontal
J7, J8, J9, J10: 2.54mm 3P; PinHeader_1x03_P2.54mm_Vertical
J11, J12, J13, J14, J15, J16: 2.54mm 5P Terminal Block; TerminalBlock_Xinya_XY308-2.54-5P_1x05_P2.54mm_Horizontal
J17, J18, J19, J20, J21, J22: JST-SH 3P; JST_SH_BM03B-SRSS-TB_1x03-1MP_P1.00mm_Vertical
Q1: NCE15P25JK; TO-252-2
R1, R2: 100k 0805 1%; R_0805_2012Metric_Pad1.20x1.40mm_HandSolder
R3: 13.3k 0805 1%; R_0805_2012Metric_Pad1.20x1.40mm_HandSolder
R4, R5, R6, R7, R8, R9: 470R 0805; R_0805_2012Metric_Pad1.20x1.40mm_HandSolder
TP1, TP2, TP3, TP4, TP5, TP6: TestPoint; TestPoint_Pad_D1.5mm
U1: 3.2~32V -> 5.1V 5A; Buck_Converter_54x24mm

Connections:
+3V3: A1.35 (ADC_VREF), A1.36 (3V3), C4.1, J17.2, J18.2, J19.2, J20.2, J21.2, J22.2, TP2.1 (1_1)
+5.1V: A1.39 (VSYS), C2.1, C3.1, C8.1, D3.1 (A1), D7.2 (A), F2.2, J2.2 (5V), J2.4 (5V), TP5.1 (1_1)
+7.5V: C5.1, D6.2 (A), J6.2, J7.2, J8.2, J9.2, J10.2, TP4.1 (1_1)
+12V: C6.1, D2.2 (A), D5.2 (A), J4.2, J11.5, J12.5, J13.5, J14.5, J15.5, J16.5, TP3.1 (1_1)
+BATT: C1.1, D1.1 (K), D4.2 (A), J3.2, J5.2, Q1.3 (S), R2.1, TP1.1 (1_1)
/ADC_IN: A1.31 (GPIO26_ADC0), C9.1, R2.2, R3.1, TP6.1 (1_1)
/BLDC_0: A1.22 (GPIO17), J11.3
/BLDC_1: A1.14 (GPIO10), J12.3
/BLDC_2: A1.11 (GPIO8), J13.3
/BLDC_3: A1.9 (GPIO6), J14.3
/BLDC_4: A1.6 (GPIO4), J15.3
/BLDC_5: A1.4 (GPIO2), J16.3
/ENC_0: A1.24 (GPIO18), J17.3
/ENC_1: A1.25 (GPIO19), J18.3
/ENC_2: A1.26 (GPIO20), J19.3
/ENC_3: A1.27 (GPIO21), J20.3
/ENC_4: A1.32 (GPIO27_ADC1), J21.3
/ENC_5: A1.34 (GPIO28_ADC2), J22.3
/PICO_EN: A1.30 (RUN), J2.32 (GPIO12/PWM0)
/PICO_INT: A1.29 (GPIO22), J2.33 (GPIO13/PWM1)
/REV_0: A1.21 (GPIO16), J11.2
/REV_1: A1.15 (GPIO11), J12.2
/REV_2: A1.12 (GPIO9), J13.2
/REV_3: A1.10 (GPIO7), J14.2
/REV_4: A1.7 (GPIO5), J15.2
/REV_5: A1.5 (GPIO3), J16.2
/SERVO_0: A1.16 (GPIO12), J7.3
/SERVO_1: A1.17 (GPIO13), J8.3
/SERVO_2: A1.19 (GPIO14), J9.3
/SERVO_3: A1.20 (GPIO15), J10.3
/UART_RX: A1.2 (GPIO1), J2.10 (GPIO15/UART_RXD)
/UART_TX: A1.1 (GPIO0), J2.8 (GPIO14/UART_TXD)
GND: A1.3 (GND), A1.8 (GND), A1.13 (GND), A1.18 (GND), A1.23 (GND), A1.28 (GND), A1.33 (AGND), A1.38 (GND), C1.2, C2.2, C3.2, C4.2, C5.2, C6.2, C7.2, C8.2, C9.2, D3.2 (A2), H1.1 (1_1), H2.1 (1_1), H3.1 (1_1), J1.1, J1.MP (MountPin), J2.6 (GND), J2.9 (GND), J2.14 (GND), J2.20 (GND), J2.25 (GND), J2.30 (GND), J2.34 (GND), J2.39 (GND), J3.1, J3.MP (MountPin), J4.1, J4.MP (MountPin), J5.1, J5.MP (MountPin), J6.1, J6.MP (MountPin), J7.1, J8.1, J9.1, J10.1, J11.1, J12.1, J13.1, J14.1, J15.1, J16.1, J17.1, J18.1, J19.1, J20.1, J21.1, J22.1, R1.2, R3.2, R6.1, R7.1, R8.1, R9.1, U1.2 (-VDC), U1.3 (VIN-)
unnamed: D1.2 (A), Q1.1 (G), R1.1
unnamed: C7.1, D2.1 (K), U1.4 (VIN+)
unnamed: D4.1 (K), R4.2
unnamed: D5.1 (K), R5.2
unnamed: D6.1 (K), R8.2
unnamed: D7.1 (K), R9.2
unnamed: F1.1, J1.2
unnamed: F1.2, Q1.2 (D)
unnamed: R4.1, R6.2
unnamed: R5.1, R7.2
unnamed: F2.1, U1.1 (+VDC)

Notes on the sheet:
Adjustable XL4015 buck converter module. Change until Raspberry Pi 5V pin is exactly 5.1V
External DC/DC Converter Recommended >10 A
Recommended 36GP-3626 43RPM 12V w/ built-in PWM speed controller
Recommended ST3215-7.4V Servo
External DC/DC Converter Recommended >10.8 A

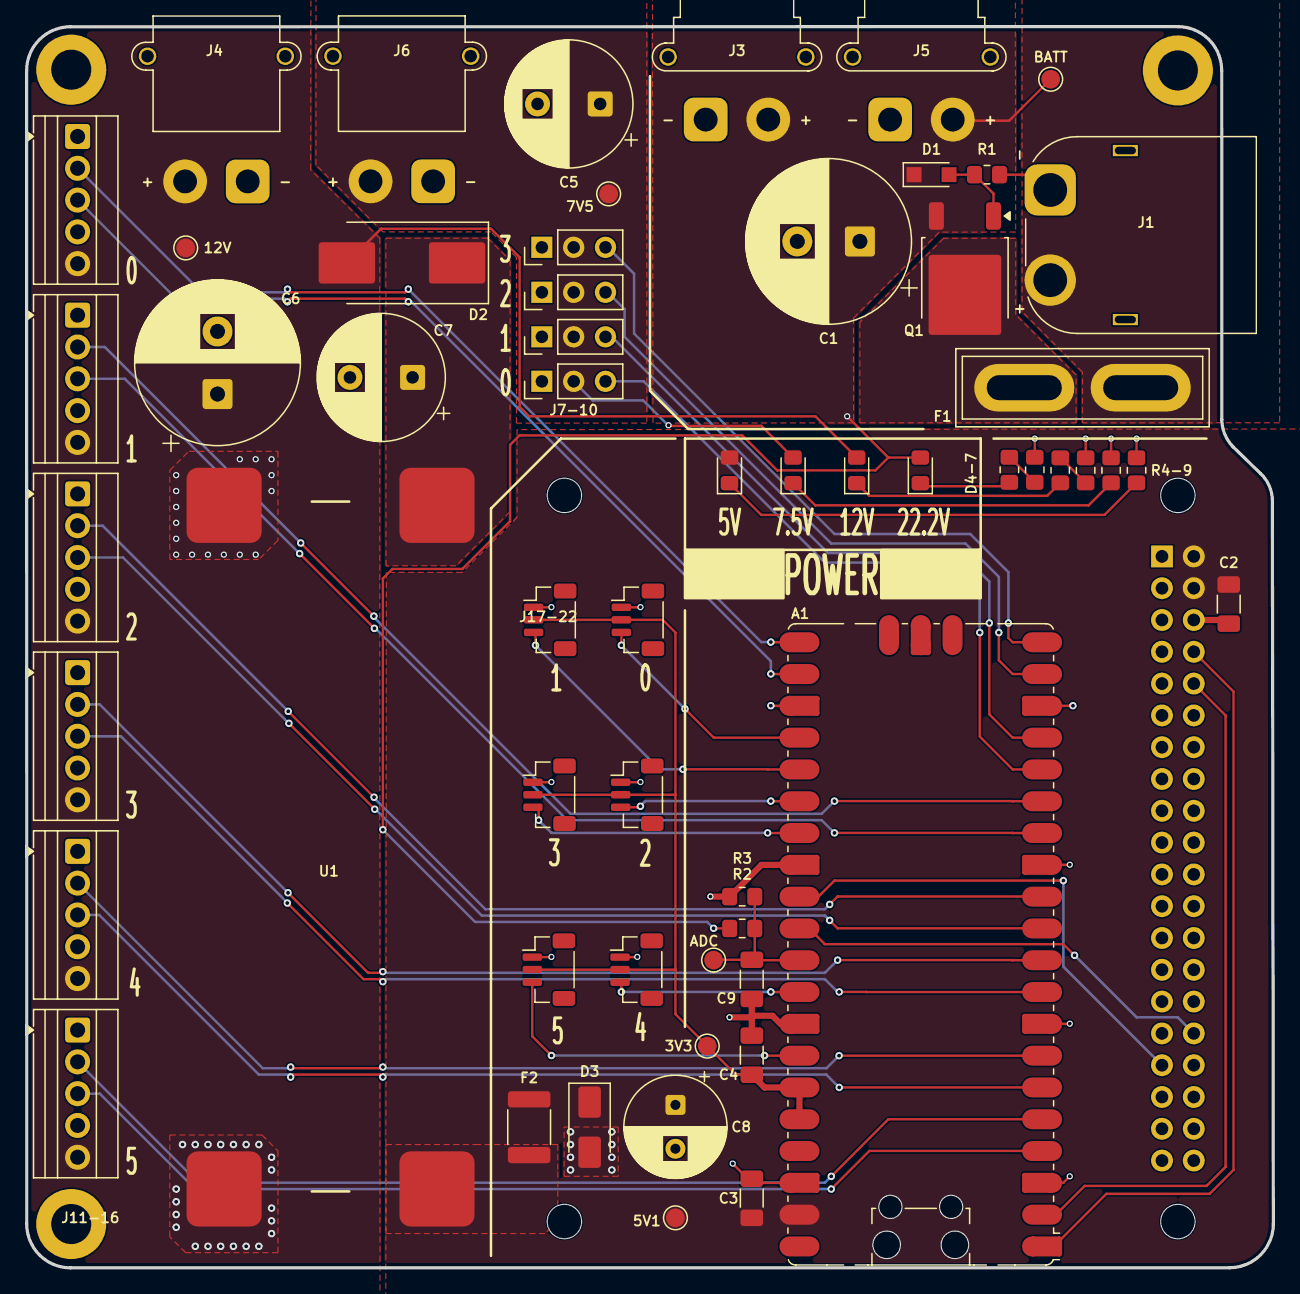
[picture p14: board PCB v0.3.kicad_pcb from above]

Board: 2 copper layers, 99.6 x 99.1 mm, 61 parts (0 on the bottom side), 44 nets.

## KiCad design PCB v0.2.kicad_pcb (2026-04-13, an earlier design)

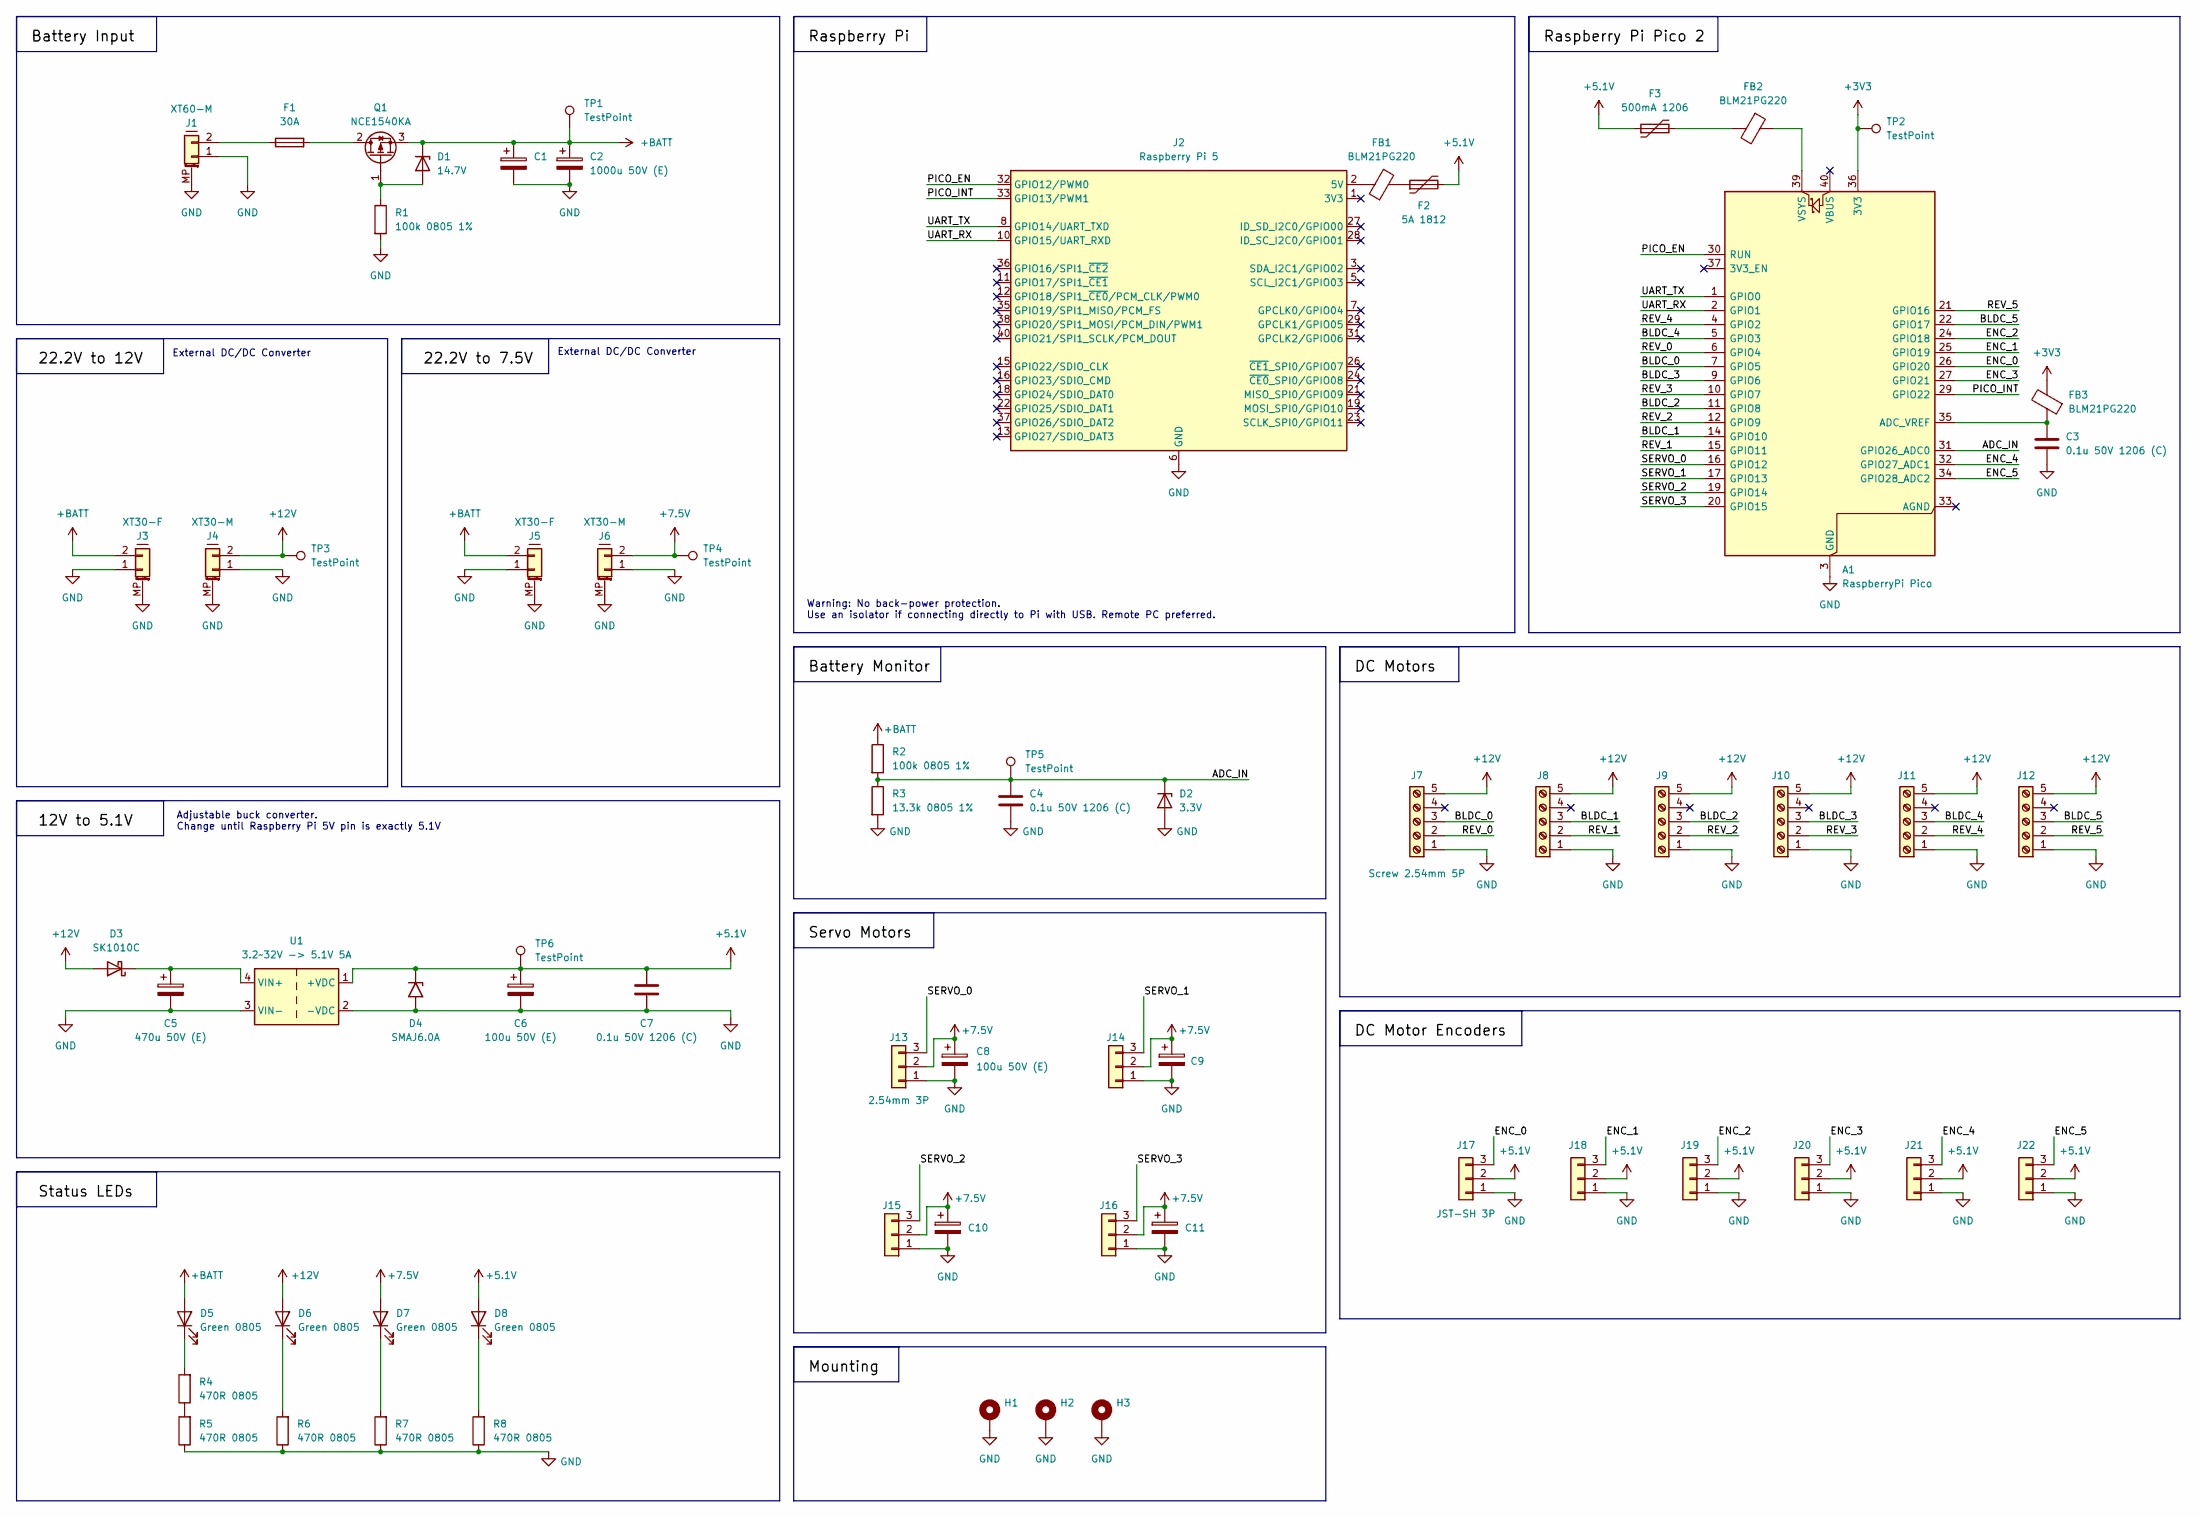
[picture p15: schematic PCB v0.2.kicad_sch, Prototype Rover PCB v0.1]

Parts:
A1: RaspberryPi Pico; RaspberryPi_Pico_SMD_HandSolder
C1, C2: 1000u 50V (E); CP_Radial_D13.0mm_P5.00mm
C3, C4, C7: 0.1u 50V 1206 (C); C_1206_3216Metric_Pad1.33x1.80mm_HandSolder
C5: 470u 50V (E); CP_Radial_D10.0mm_P5.00mm
C6, C8, C9, C10, C11: 100u 50V (E); CP_Radial_D8.0mm_P3.50mm
D1: 14.7V; Nexperia_CFP3_SOD-123W
D2: 3.3V; Nexperia_CFP3_SOD-123W
D3: SK1010C; D_SMC_Handsoldering
D4: SMAJ6.0A; D_SMA
D5, D6, D7, D8: Green 0805; LED_0805_2012Metric_Pad1.15x1.40mm_HandSolder
F1: 30A; FuseHolder_Blade_ATO_Littelfuse_FLR_178.6165
F2: 5A 1812; Fuse_1206_3216Metric
F3: 500mA 1206; Fuse_1206_3216Metric
FB1, FB2, FB3: BLM21PG220; L_0805_2012Metric_Pad1.05x1.20mm_HandSolder
H1, H2, H3: M3 3.2mm; MountingHole_3.2mm_M3_DIN965_Pad
J1: XT60-M; AMASS_XT60PW-M_1x02_P7.20mm_Horizontal
J2: Raspberry Pi 5; Raspberry_Pi_5
J3, J5: XT30-F; AMASS_XT30PW-F_1x02_P2.50mm_Horizontal
J4, J6: XT30-M; AMASS_XT30PW-M_1x02_P2.50mm_Horizontal
J7, J8, J9, J10, J11, J12: Screw 2.54mm 5P; TerminalBlock_Xinya_XY308-2.54-5P_1x05_P2.54mm_Horizontal
J13, J14, J15, J16: 2.54mm 3P; PinHeader_1x03_P2.54mm_Vertical
J17, J18, J19, J20, J21, J22: JST-SH 3P; JST_SH_BM03B-SRSS-TB_1x03-1MP_P1.00mm_Vertical
Q1: NCE1540KA; TO-252-2
R1, R2: 100k 0805 1%; R_0805_2012Metric_Pad1.20x1.40mm_HandSolder
R3: 13.3k 0805 1%; R_0805_2012Metric_Pad1.20x1.40mm_HandSolder
R4, R5, R6, R7, R8: 470R 0805; R_0805_2012Metric_Pad1.20x1.40mm_HandSolder
TP1, TP2, TP3, TP4, TP5, TP6: TestPoint; TestPoint_Pad_D1.5mm
U1: 3.2~32V -> 5.1V 5A; Buck_Converter_54x24mm

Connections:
+3V3: A1.36 (3V3), FB3.2, TP2.1 (1_1)
+5.1V: C6.1, C7.1, D4.1 (A1), D8.2 (A), F2.2, F3.1, J17.2, J18.2, J19.2, J20.2, J21.2, J22.2, TP6.1 (1_1), U1.1 (+VDC)
+7.5V: C8.1, C9.1, C10.1, C11.1, D7.2 (A), J6.2, J13.2, J14.2, J15.2, J16.2, TP4.1 (1_1)
+12V: D3.2 (A), D6.2 (A), J4.2, J7.5, J8.5, J9.5, J10.5, J11.5, J12.5, TP3.1 (1_1)
+BATT: C1.1, C2.1, D1.1 (K), D5.2 (A), J3.2, J5.2, Q1.3 (S), R2.1, TP1.1 (1_1)
/ADC_IN: A1.31 (GPIO26_ADC0), C4.1, D2.1 (K), R2.2, R3.1, TP5.1 (1_1)
/BLDC_0: A1.7 (GPIO5), J7.3
/BLDC_1: A1.14 (GPIO10), J8.3
/BLDC_2: A1.11 (GPIO8), J9.3
/BLDC_3: A1.9 (GPIO6), J10.3
/BLDC_4: A1.5 (GPIO3), J11.3
/BLDC_5: A1.22 (GPIO17), J12.3
/ENC_0: A1.26 (GPIO20), J17.3
/ENC_1: A1.25 (GPIO19), J18.3
/ENC_2: A1.24 (GPIO18), J19.3
/ENC_3: A1.27 (GPIO21), J20.3
/ENC_4: A1.32 (GPIO27_ADC1), J21.3
/ENC_5: A1.34 (GPIO28_ADC2), J22.3
/PICO_EN: A1.30 (RUN), J2.32 (GPIO12/PWM0)
/PICO_INT: A1.29 (GPIO22), J2.33 (GPIO13/PWM1)
/REV_0: A1.6 (GPIO4), J7.2
/REV_1: A1.15 (GPIO11), J8.2
/REV_2: A1.12 (GPIO9), J9.2
/REV_3: A1.10 (GPIO7), J10.2
/REV_4: A1.4 (GPIO2), J11.2
/REV_5: A1.21 (GPIO16), J12.2
/SERVO_0: A1.16 (GPIO12), J13.3
/SERVO_1: A1.17 (GPIO13), J14.3
/SERVO_2: A1.19 (GPIO14), J15.3
/SERVO_3: A1.20 (GPIO15), J16.3
/UART_RX: A1.2 (GPIO1), J2.10 (GPIO15/UART_RXD)
/UART_TX: A1.1 (GPIO0), J2.8 (GPIO14/UART_TXD)
GND: A1.3 (GND), A1.8 (GND), A1.13 (GND), A1.18 (GND), A1.23 (GND), A1.28 (GND), A1.38 (GND), C1.2, C2.2, C3.2, C4.2, C5.2, C6.2, C7.2, C8.2, C9.2, C10.2, C11.2, D2.2 (A), D4.2 (A2), H1.1 (1_1), H2.1 (1_1), H3.1 (1_1), J1.1, J1.MP (MountPin), J2.6 (GND), J2.9 (GND), J2.14 (GND), J2.20 (GND), J2.25 (GND), J2.30 (GND), J2.34 (GND), J2.39 (GND), J3.1, J3.MP (MountPin), J4.1, J4.MP (MountPin), J5.1, J5.MP (MountPin), J6.1, J6.MP (MountPin), J7.1, J8.1, J9.1, J10.1, J11.1, J12.1, J13.1, J14.1, J15.1, J16.1, J17.1, J18.1, J19.1, J20.1, J21.1, J22.1, R1.2, R3.2, R5.1, R6.1, R7.1, R8.1, U1.2 (-VDC), U1.3 (VIN-)
unnamed: A1.35 (ADC_VREF), C3.1, FB3.1
unnamed: A1.39 (VSYS), FB2.1
unnamed: D1.2 (A), Q1.1 (G), R1.1
unnamed: C5.1, D3.1 (K), U1.4 (VIN+)
unnamed: D5.1 (K), R4.2
unnamed: D6.1 (K), R6.2
unnamed: D7.1 (K), R7.2
unnamed: D8.1 (K), R8.2
unnamed: F2.1, FB1.2
unnamed: F3.2, FB2.2
unnamed: FB1.1, J2.2 (5V), J2.4 (5V)
unnamed: F1.1, J1.2
unnamed: F1.2, Q1.2 (D)
unnamed: R4.1, R5.2

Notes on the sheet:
Warning: No back-power protection. Use an isolator if connecting directly to Pi with USB. Remote PC preferred.
Adjustable buck converter. Change until Raspberry Pi 5V pin is exactly 5.1V
External DC/DC Converter

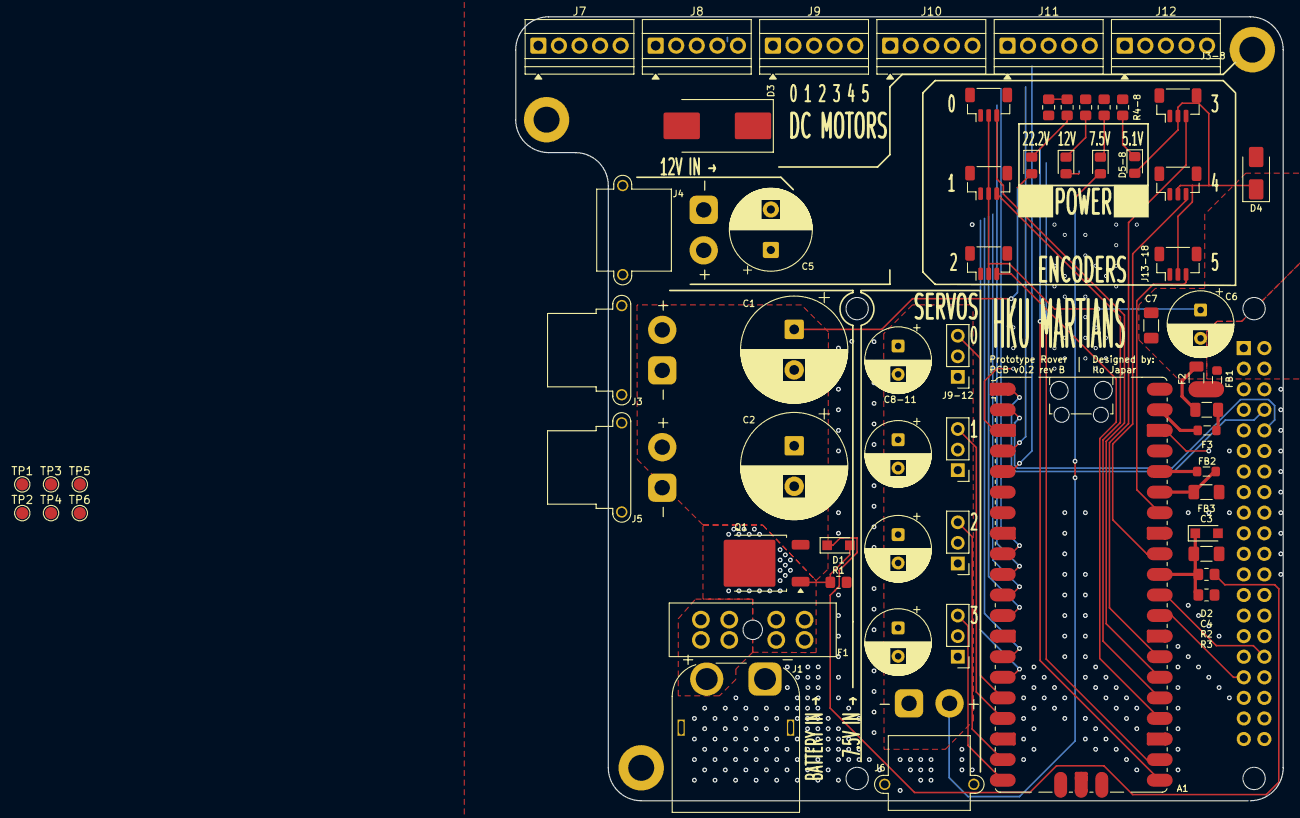
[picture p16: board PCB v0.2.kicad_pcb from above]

Board: 2 copper layers, 94.7 x 96.8 mm, 67 parts (1 on the bottom side), 47 nets.

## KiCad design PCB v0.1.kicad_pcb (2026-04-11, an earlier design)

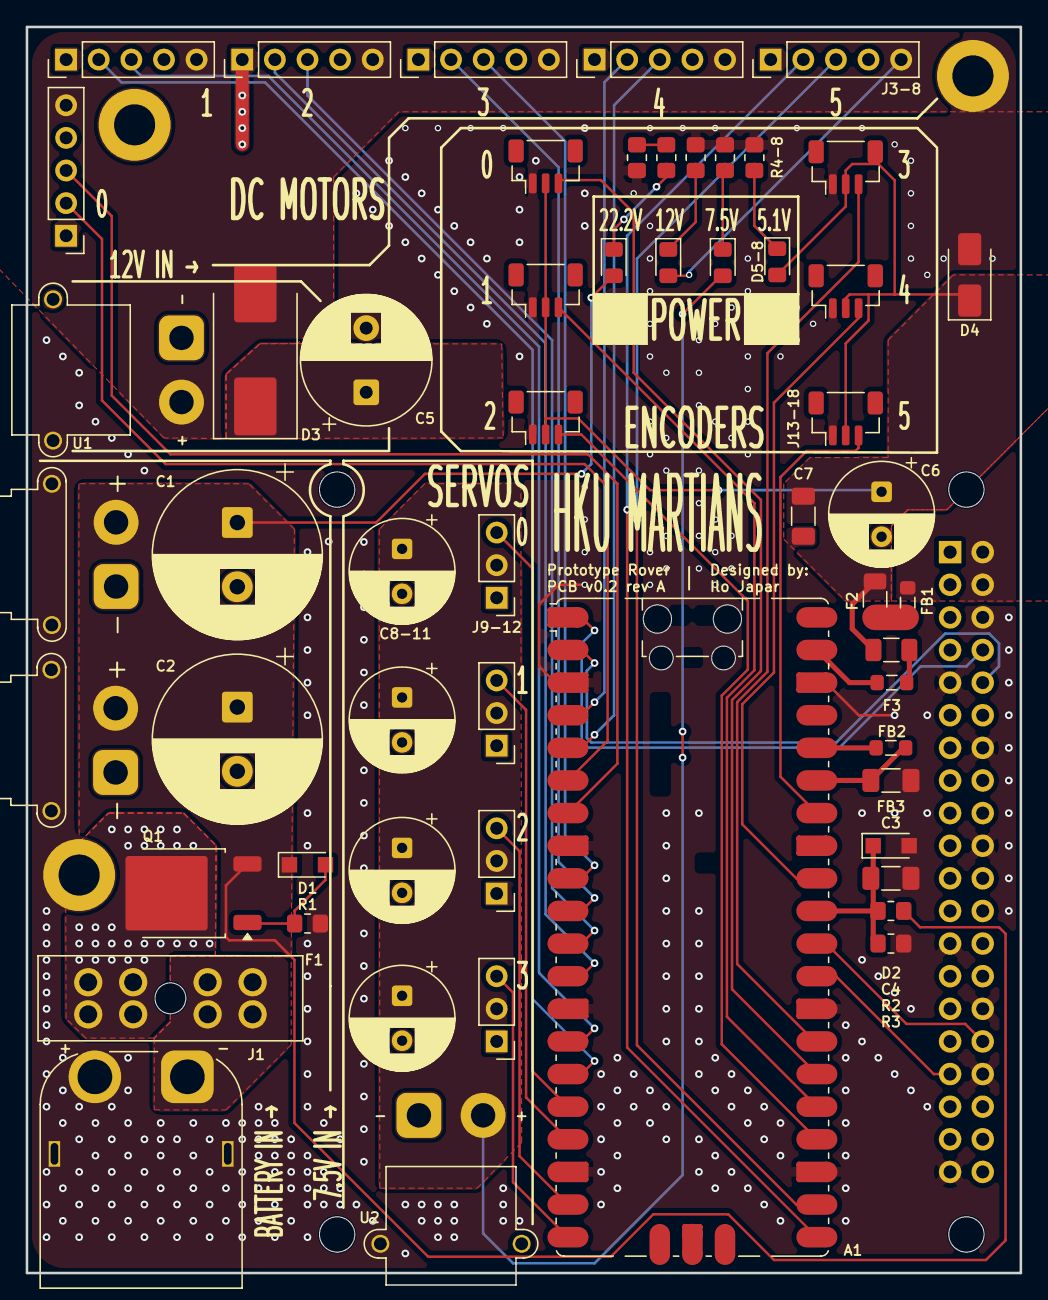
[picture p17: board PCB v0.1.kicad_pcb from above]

Board: 2 copper layers, 77.4 x 97.0 mm, 60 parts (0 on the bottom side), 47 nets.

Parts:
A1: RaspberryPi Pico; RaspberryPi_Pico_SMD_HandSolder
C1, C2: 1000u 50V (E); CP_Radial_D13.0mm_P5.00mm
C3, C4, C7: 0.1u 50V 1206 (C); C_1206_3216Metric_Pad1.33x1.80mm_HandSolder
C5: 470u 50V (E); CP_Radial_D10.0mm_P5.00mm
C6, C8, C9, C10, C11: 100u 50V (E); CP_Radial_D8.0mm_P3.50mm
D1: 14.7V; Nexperia_CFP3_SOD-123W
D2: 3.3V; Nexperia_CFP3_SOD-123W
D3: SK1010C; D_SMC_Handsoldering
D4: SMAJ6.0A; D_SMA
D5, D6, D7, D8: Green 0805; LED_0805_2012Metric_Pad1.15x1.40mm_HandSolder
F1: 30A; FuseHolder_Blade_ATO_Littelfuse_FLR_178.6165
F2: 5A 1812; Fuse_1206_3216Metric
F3: 500mA 1206; Fuse_1206_3216Metric
FB1, FB2, FB3: BLM21PG220; L_0805_2012Metric_Pad1.05x1.20mm_HandSolder
H1, H2, H3: M3 3.2mm; MountingHole_3.2mm_M3_DIN965_Pad
J1: XT60 M (Horizontal); AMASS_XT60PW-M_1x02_P7.20mm_Horizontal
J2: Raspberry Pi 5; Raspberry_Pi_5
J3: Screw 2.54mm 5P; PinHeader_1x05_P2.54mm_Vertical
J4, J5, J6, J7, J8: Screw Terminal 5P; PinHeader_1x05_P2.54mm_Vertical
J9, J10, J11, J12: 2.54mm 3P; PinHeader_1x03_P2.54mm_Vertical
J13, J14, J15, J16, J17, J18: JST-SH 3P; JST_SH_BM03B-SRSS-TB_1x03-1MP_P1.00mm_Vertical
Q1: NCE1540KA; TO-252-2
R1, R2: 100k 0805 1%; R_0805_2012Metric_Pad1.20x1.40mm_HandSolder
R3: 13.3k 0805 1%; R_0805_2012Metric_Pad1.20x1.40mm_HandSolder
R4, R5, R6, R7, R8: 470R 0805; R_0805_2012Metric_Pad1.20x1.40mm_HandSolder
U1, U2: AMASS_XT30PW-F_1x02_P2.50mm_Horizontal
U1#2, U2#2: AMASS_XT30PW-M_1x02_P2.50mm_Horizontal

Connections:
+3V3: A1.36 (3V3), FB3.2
+5.1V: C6.1, C7.1, D4.1 (A1), D8.2 (A), F2.2, F3.1, J13.2, J14.2, J15.2, J16.2, J17.2, J18.2
+7.5V: C8.1, C9.1, C10.1, C11.1, D7.2 (A), J9.2, J10.2, J11.2, J12.2, U2#2.1
+12V: D3.2 (A), D6.2 (A), J3.5, J4.5, J5.5, J6.5, J7.5, J8.5, U1#2.1
+BATT: C1.1, C2.1, D1.1 (K), D5.2 (A), Q1.3 (S), R2.1, U1.4, U2.4
/ADC_IN: A1.31 (GPIO26_ADC0), C4.1, D2.1 (K), R2.2, R3.1
/BLDC_0: A1.7 (GPIO5), J3.3
/BLDC_1: A1.14 (GPIO10), J4.3
/BLDC_2: A1.11 (GPIO8), J5.3
/BLDC_3: A1.9 (GPIO6), J6.3
/BLDC_4: A1.5 (GPIO3), J7.3
/BLDC_5: A1.22 (GPIO17), J8.3
/ENC_0: A1.26 (GPIO20), J13.3
/ENC_1: A1.25 (GPIO19), J14.3
/ENC_2: A1.24 (GPIO18), J15.3
/ENC_3: A1.27 (GPIO21), J16.3
/ENC_4: A1.32 (GPIO27_ADC1), J17.3
/ENC_5: A1.34 (GPIO28_ADC2), J18.3
/PICO_EN: A1.30 (RUN), J2.32 (GPIO12/PWM0)
/PICO_INT: A1.29 (GPIO22), J2.33 (GPIO13/PWM1)
/REV_0: A1.6 (GPIO4), J3.2
/REV_1: A1.15 (GPIO11), J4.2
/REV_2: A1.12 (GPIO9), J5.2
/REV_3: A1.10 (GPIO7), J6.2
/REV_4: A1.4 (GPIO2), J7.2
/REV_5: A1.21 (GPIO16), J8.2
/SERVO_0: A1.16 (GPIO12), J9.3
/SERVO_1: A1.17 (GPIO13), J10.3
/SERVO_2: A1.19 (GPIO14), J11.3
/SERVO_3: A1.20 (GPIO15), J12.3
/UART_RX: A1.2 (GPIO1), J2.10 (GPIO15/UART_RXD)
/UART_TX: A1.1 (GPIO0), J2.8 (GPIO14/UART_TXD)
GND: A1.3 (GND), A1.8 (GND), A1.13 (GND), A1.18 (GND), A1.23 (GND), A1.28 (GND), A1.38 (GND), C1.2, C2.2, C3.2, C4.2, C5.2, C6.2, C7.2, C8.2, C9.2, C10.2, C11.2, D2.2 (A), D4.2 (A2), H1.1 (1_1), H2.1 (1_1), H3.1 (1_1), J1.2, J2.6 (GND), J2.9 (GND), J2.14 (GND), J2.20 (GND), J2.25 (GND), J2.30 (GND), J2.34 (GND), J2.39 (GND), J3.1, J4.1, J5.1, J6.1, J7.1, J8.1, J9.1, J10.1, J11.1, J12.1, J13.1, J14.1, J15.1, J16.1, J17.1, J18.1, R1.2, R3.2, R5.1, R6.1, R7.1, R8.1, U1.3, U1#2.2, U2.3, U2#2.2
unnamed: A1.35 (ADC_VREF), C3.1, FB3.1
unnamed: A1.39 (VSYS), FB2.1
unnamed: D1.2 (A), Q1.1 (G), R1.1
unnamed: C5.1, D3.1 (K)
unnamed: D5.1 (K), R4.2
unnamed: D6.1 (K), R6.2
unnamed: D7.1 (K), R7.2
unnamed: D8.1 (K), R8.2
unnamed: F2.1, FB1.2
unnamed: F3.2, FB2.2
unnamed: FB1.1, J2.2 (5V), J2.4 (5V)
unnamed: F1.1, J1.1
unnamed: F1.2, Q1.2 (D)
unnamed: R4.1, R5.2

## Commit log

2026-04-08 Began adding footprints & datasheets
    [Battery Monitor v0.1.kicad_sch]
2026-04-08 Finished design. TODO: Servo actually 7.4V. Needs fix
    [Battery Monitor v0.1.kicad_sch]
2026-04-09 Todo: 7.5V buck collides with RPi
    [Battery Monitor v0.1 Control.kicad_sch, Battery Monitor v0.1.kicad_sch]
2026-04-10 Rev A finished. docs made, BOM made.
    [PCB v0.1-B_Cu.gbl, PCB v0.1-B_Mask.gbs, PCB v0.1-B_Paste.gbp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]
2026-04-10 Updated README
    Updated description to specify design for small 6-wheel rovers with a 4-DoF robotic arm.
2026-04-10 Change PCB image in README
    Updated PCB image link in README.
2026-04-10 Revise power specifications and remove protection features
    Updated power tree specifications and added details about external module connections. Removed protection features section.
2026-04-11 Created new layout, fixed XT30 polarity
    [PCB v0.1.kicad_pcb, PCB v0.1.kicad_sch]
2026-04-11 v0.2. Corrected XT30 polarity, less than 10x10cm in size
    [PCB v0.1-B_Cu.gbl, PCB v0.1-B_Mask.gbs, PCB v0.1-B_Paste.gbp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]
2026-04-11 v0.2. Added dimensions. Replaced image
    Updated PCB image link and corrected text formatting.
2026-04-13 U1 symbol was not in v0.2
    [PCB v0.2.kicad_pcb, PCB v0.2.kicad_sch]
2026-05-08 Changed PCB
    [PCB v0.2-B_Cu.gbl, PCB v0.2-B_Mask.gbs, PCB v0.2-B_Paste.gbp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]
2026-05-08 Finished v0.3 SCH
    [PCB v0.3.csv, PCB v0.3.kicad_pcb, PCB v0.3.kicad_sch]
2026-05-08 Laid out power circuitry
    [PCB v0.3.kicad_pcb, PCB v0.3.kicad_sch]
2026-05-08 Finished laying out
    [PCB v0.3.kicad_pcb, PCB v0.3.kicad_sch]
2026-05-08 Power planes, began routing
    [PCB v0.3.kicad_pcb, PCB v0.3.kicad_sch]
2026-05-09 Finished layout and routing. Begun documentation
    [PCB v0.3-B_Cu.gbl, PCB v0.3-B_Mask.gbs, PCB v0.3-B_Paste.gbp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]
2026-05-13 Add documentation and gerbers
    [PCB v0.3.kicad_pcb]
2026-05-13 Fix image link and update power tree specifications
    Updated image link and corrected power specifications.
2026-05-13 Update description of Power Distribution Board
